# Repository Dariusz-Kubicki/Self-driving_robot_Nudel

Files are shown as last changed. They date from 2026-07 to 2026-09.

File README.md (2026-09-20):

# Self-driving_robot_Nudel

**Nudel** to mój pierwszy projekt robotyczny: czterokołowy robot mobilny budowany na bazie zestawu z AliExpress i rozwijany jako line follower. Jego pierwszym zadaniem jest samodzielne poruszanie się po czarnej linii przy użyciu czterech cyfrowych czujników podczerwieni.

Projekt nadal jest rozwijany. Robot poprawnie uruchamia napęd i reaguje na czujniki, ale algorytm oraz wartości PWM wymagają dalszego strojenia na większym torze z łagodniejszymi zakrętami.

## Aktualny stan projektu

- podwozie 4WD zostało złożone i okablowane;
- pierwotny sterownik L293D został zastąpiony modułem DRV8833;
- zamontowano wydrukowaną podstawkę Arduino i dystanse czujników IR;
- koszyk 4×AA został zastąpiony koszykiem 6×AA;
- Arduino otrzymało osobne zasilanie 9 V przez gniazdo DC;
- dodano kondensatory ograniczające zakłócenia zasilania;
- powstała plansza testowa z 12 połączonych kartek A4;
- działa podstawowy program reagujący na cztery czujniki IR;
- trwają testy prędkości i zachowania robota na zakrętach.

Najbliższy test zostanie wykonany na dużym, łagodnym okręgu. Obecny tor ma zbyt ciasne zakręty dla długiego podwozia 4WD, które podczas skręcania musi pokonać duże tarcie boczne czterech opon.

## Cel projektu

Celem projektu jest praktyczna nauka podstaw robotyki i zbudowanie pierwszego autonomicznego pojazdu. Podczas pracy uczę się:

- sterowania silnikami DC za pomocą mostka H;
- generowania sygnału PWM i doboru prędkości silników;
- konfiguracji oraz kalibracji cyfrowych czujników IR;
- projektowania algorytmu line followera;
- diagnozowania spadków napięcia, zakłóceń i resetów mikrokontrolera;
- lutowania, prowadzenia przewodów i prototypowania;
- projektowania prostych elementów mechanicznych do druku 3D;
- dokumentowania kolejnych wersji konstrukcji i kodu.

W przyszłości planuję rozbudować Nudla o czujnik odległości HC-SR04, serwomechanizm SG90, a w dalszej perspektywie również kamerę.

### Skąd nazwa „Nudel”?

Nazwa robota upamiętnia mojego pierwszego kota, który wabił się Nudel. Uznałem, że będzie to dobre imię dla mojego debiutanckiego projektu robotycznego.

## Elementy projektu

Podstawą konstrukcji jest [zestaw z AliExpress](https://pl.aliexpress.com/item/1005002223616703.html), który został przeze mnie zmodyfikowany.

### Elementy pochodzące z zestawu

- klon Arduino UNO R3;
- cztery czujniki IR;
- płytka z komparatorami i potencjometrami do regulacji czujników;
- cztery silniki DC z przekładniami TT;
- czujnik ultradźwiękowy HC-SR04;
- serwomechanizm SG90;
- nakładka Arduino UNO Sensor Shield V5.0;
- akrylowe podwozie, koła i elementy montażowe;
- pierwotny koszyk na cztery baterie AA.

### Elementy dodane lub zmienione

- dwukanałowy sterownik silników DRV8833;
- koszyk na sześć baterii AA;
- osobne źródło 9 V dla Arduino;
- kondensatory filtrujące zasilanie;
- wydrukowana podstawka pod Arduino;
- wydrukowane dystanse obniżające czujniki IR;
- nowe przewody i poprawione połączenia lutowane.

## Druk 3D

Drukarkę 3D kupiłem już w trakcie budowy robota. Wykorzystałem ją do wykonania elementów dopasowanych do tej konstrukcji:

- [podstawka pod Arduino](Ard.stl);
- [dystanse do czujników IR](dystanse_do_sensorow.stl).

Podstawka porządkuje montaż elektroniki, a dystanse umieszczają czujniki bliżej podłoża. Zbyt duża odległość od planszy powodowała niestabilne wykrywanie czarnej taśmy.

Elementy drukowane nie są niezbędne. Arduino można przykręcić bezpośrednio do podwozia lub zastosować gotowy uchwyt, a wysokość czujników ustawić za pomocą zwykłych dystansów montażowych.

## Zasilanie

Napęd i elektronika korzystają obecnie z oddzielnych źródeł zasilania:

```text
6×AA ───────────────> zasilanie silników przez DRV8833

9 V przez gniazdo DC ─> Arduino UNO i układ sterujący

GND Arduino ─────────> GND DRV8833
```

Wspólna masa jest potrzebna, aby sygnały sterujące z Arduino miały prawidłowy poziom odniesienia.

Rozdzielenie zasilania rozwiązało problem resetowania Arduino podczas jednoczesnego uruchamiania silników. Wcześniej impuls prądowy napędu powodował spadek napięcia całego układu. Zwiększenie samej liczby baterii nie wystarczyło, ponieważ problem dotyczył także wydajności prądowej i wspólnej linii zasilania.

## Połączenia z Arduino

Aktualny program korzysta z następujących pinów:

| Element | Pin Arduino |
|---|---:|
| Lewy czujnik IR | 8 |
| Środkowy lewy czujnik IR | 7 |
| Środkowy prawy czujnik IR | 4 |
| Prawy czujnik IR | 2 |
| DRV8833 — LIN1 | 5 |
| DRV8833 — LIN2 | 3 |
| DRV8833 — RIN1 | 9 |
| DRV8833 — RIN2 | 6 |

Wszystkie cztery wejścia sterownika silników podłączono do pinów obsługujących PWM w Arduino UNO. Dzięki temu program może regulować prędkość obu stron napędu oraz zmieniać ich kierunek.

## Oprogramowanie

Aktualny kod znajduje się w pliku [Robot_Nudel.ino](Robot_Nudel.ino).

Program:

1. odczytuje stany czterech czujników IR;
2. wybiera jazdę prosto, lekką korektę, mocny skręt albo zatrzymanie;
3. steruje lewą i prawą stroną napędu przez DRV8833;
4. podczas mocnego skrętu może napędzać obie strony w przeciwnych kierunkach, aby zmniejszyć promień obrotu.

Aktualne wartości PWM są eksperymentalne. Po ustabilizowaniu zasilania silniki zaczęły pracować znacznie pewniej, dlatego wcześniejsze ustawienia prędkości trzeba było dobrać ponownie.

### Ważna uwaga dotycząca czujników

Stan logiczny czujnika zależy od ustawienia komparatorów i zastosowanego modułu. Przed dalszym strojeniem programu trzeba jednoznacznie sprawdzić w monitorze portu szeregowego, jaki stan (`LOW` lub `HIGH`) odpowiada czarnej taśmie, a jaki białemu podłożu. Kod i opis tej logiki powinny być ze sobą zgodne.

## Proces budowy

### 1. Złożenie podwozia

Prace rozpocząłem od zamontowania przekładni TT, silników, kół i czujników IR.

Z podwoziem wiąże się zabawna historia. Dopiero po pełnym złożeniu konstrukcji zorientowałem się, że akryl jest przezroczysty. Wcześniej uznałem brązową folię ochronną za docelowy kolor materiału, dlatego musiałem rozmontować całość, aby ją usunąć.

Podczas pierwszego montażu pominąłem także gumowe elementy zabezpieczające silniki. Założyłem je później pęsetą na niemal ukończonym robocie. Konstrukcja i tak została następnie ponownie rozebrana podczas wymiany sterownika silników.

### 2. Montaż czujników

Czujniki zamontowane bezpośrednio przy podwoziu znajdowały się zbyt wysoko nad planszą. Zaprojektowałem więc dystanse, które obniżyły moduły i poprawiły powtarzalność odczytów.

Podczas wykonywania otworów dwukrotnie uszkodziłem akrylowe podwozie. Pęknięcia udało się skleić, ale ten etap pokazał, że akryl wymaga ostrożnej obróbki. Najbezpieczniej wiercić na małych obrotach, podeprzeć materiał, zacząć od niewielkiego otworu prowadzącego i stopniowo zwiększać średnicę. Silne podgrzewanie może odkształcić lub uszkodzić tworzywo.

### 3. Montaż elektroniki

Pierwsza wersja powstała bez wcześniejszego prototypu. Elementy były od razu lutowane i montowane na docelowym podwoziu. Utrudniło to znalezienie błędów oraz wymusiło kilkukrotne rozbieranie robota.

Po wymianie przewodów, sterownika silników i sposobu zasilania połączenia zaczęły działać stabilniej.

### 4. Budowa toru testowego

Do testów powstała duża plansza z 12 kartek A4 ułożonych w prostokąt i połączonych ze sobą. Trasę wykonano z czarnej taśmy izolacyjnej.

Pierwszy tor zawierał zakręty zbyt ciasne dla obecnej konstrukcji. Czterokołowe podwozie jest długie, a podczas skręcania wszystkie koła pozostają ustawione równolegle, przez co opony muszą częściowo ślizgać się po podłożu. Kolejna trasa będzie miała kształt dużego, łagodnego okręgu.

## Napotkane problemy

### 1. Brak odpowiedniego sterownika silników

W zestawie nie znalazł się sterownik napędu. Pierwsza wersja robota korzystała więc z układu L293D pochodzącego z zestawu kursu Arduino Forbota.

L293D powodował duży spadek napięcia na wyjściach i nie radził sobie dobrze z czterema silnikami TT połączonymi parami. Robot poruszał się bardzo wolno i nie miał wystarczającego momentu do skręcania. Przy lekkim napędzie 2WD układ mógłby działać, ale zależy to od poboru prądu konkretnych silników, szczególnie podczas rozruchu i zablokowania wału.

**Rozwiązanie:** L293D został zastąpiony modułem DRV8833, który ma mniejsze straty napięcia i lepiej nadaje się do sterowania tym napędem.

### 2. Słabe i zbyt krótkie przewody

Pierwsze przewody pochodziły z taniego zestawu. Źle znosiły lutowanie, a ich końce łatwo się uszkadzały. Część odcinków została także przycięta bez odpowiedniego zapasu, przez co po montażu były naprężone i odrywały się od połączeń.

**Rozwiązanie:** zastosowanie lepszych przewodów, pozostawienie zapasu długości oraz mechaniczne odciążenie połączeń.

### 3. Brak prototypowania

Układ został od razu zlutowany w docelowej formie. Każda większa zmiana wymagała więc rozlutowania przewodów i częściowego demontażu robota.

**Wniosek:** przed montażem docelowym warto sprawdzić osobno zasilanie, każdy kanał sterownika, kierunki wszystkich silników i odczyty czujników.

### 4. Resetowanie Arduino podczas rozruchu

Po zamontowaniu DRV8833 silniki zaczęły pobierać większy prąd przy ruszaniu. Przy wspólnym zasilaniu powodowało to spadki napięcia i wielokrotne restarty Arduino, widoczne w monitorze portu szeregowego jako powtarzający się komunikat `Start`.

Dodanie kondensatorów ograniczyło zakłócenia, ale nie usunęło głównej przyczyny.

**Rozwiązanie:** oddzielenie zasilania Arduino od obwodu silników. Arduino jest obecnie zasilane napięciem 9 V przez gniazdo DC, a napęd z koszyka 6×AA. Oba obwody mają wspólną masę.

### 5. Dobór prędkości i promienia zakrętów

Po ustabilizowaniu zasilania silniki zaczęły osiągać znacznie większą prędkość. Wartości PWM, które wcześniej ledwo poruszały robotem, przestały odpowiadać nowym warunkom testu.

Dodatkowo pierwszy tor miał zbyt mały promień zakrętów dla podwozia 4WD.

**Obecne rozwiązanie:** zmniejszenie PWM, użycie przeciwnego kierunku obrotu stron podczas mocnego skrętu oraz przygotowanie większego toru z łagodniejszymi łukami.

## Uruchomienie

1. Otwórz plik `Robot_Nudel.ino` w Arduino IDE.
2. Wybierz płytkę `Arduino Uno` i właściwy port szeregowy.
3. Wgraj program.
4. Sprawdź położenie robota oraz czujników przed włączeniem zasilania silników.
5. Umieść dwa środkowe czujniki nad linią, a skrajne nad jasnym tłem.
6. Włącz zasilanie napędu i obserwuj zachowanie na prostym odcinku przed testem pełnej trasy.

## Plan dalszych prac

- wykonać duży tor w kształcie łagodnego okręgu;
- potwierdzić poziomy logiczne czujników na czarnej i białej powierzchni;
- dostroić wartości PWM dla jazdy prosto oraz obu rodzajów skrętu;
- uzyskać kilka powtarzalnych pełnych okrążeń bez ręcznej pomocy;
- uporządkować i dodatkowo zabezpieczyć przewody;
- zastąpić testowe zasilanie Arduino rozwiązaniem docelowym;
- dodać HC-SR04 i SG90;
- rozważyć późniejszą rozbudowę o kamerę.

## Najważniejsze wnioski

- liczba baterii nie określa sama w sobie wydajności zasilania;
- prąd rozruchowy silników może resetować mikrokontroler;
- układ może działać bez obciążenia, a zawodzić po postawieniu robota na podłożu;
- kondensatory pomagają ograniczyć zakłócenia, ale nie zastępują poprawnego zasilania;
- elementy trzeba testować osobno przed zlutowaniem całego układu;
- w podwoziu 4WD geometria toru ma duży wpływ na możliwość skręcania;
- po każdej zmianie sprzętowej parametry programu mogą wymagać ponownego strojenia.

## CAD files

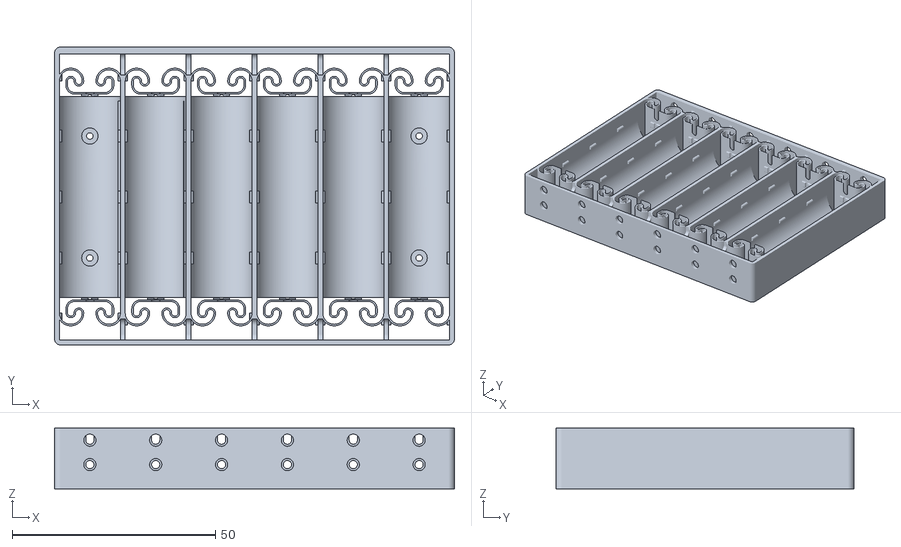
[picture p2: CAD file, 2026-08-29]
AAA_HolderX6.stl
98.4 x 73.3 x 15.0

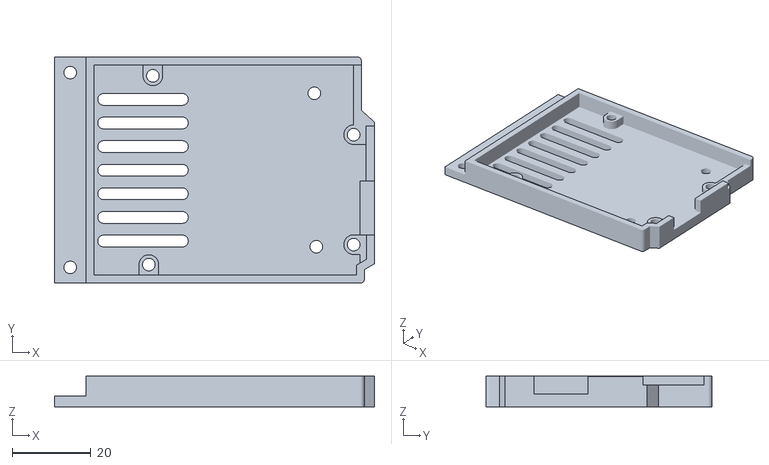
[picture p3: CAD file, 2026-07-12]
Ard.stl
81.3 x 57.5 x 7.80

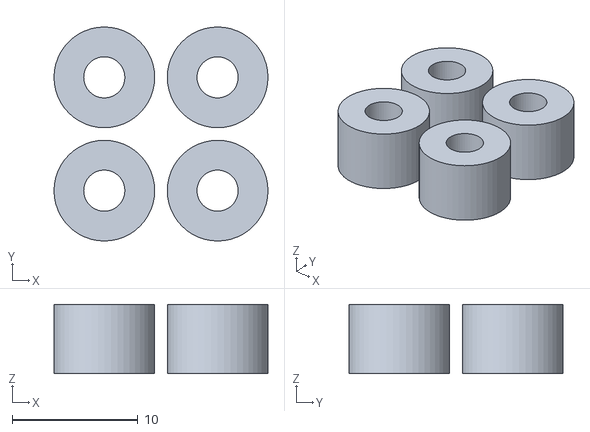
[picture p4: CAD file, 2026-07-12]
dystanse_do_sensorow.stl
17.0 x 17.0 x 5.50

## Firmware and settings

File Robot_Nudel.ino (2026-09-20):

// Piny czujników IR
#define IR_Lewy 8
#define IR_Srodek_Lewy 7
#define IR_Srodek_Prawy 4
#define IR_Prawy 2

// Piny silników
#define LIN1 5
#define LIN2 3
#define RIN1 9
#define RIN2 6

void setup() {
  pinMode(IR_Lewy, INPUT);
  pinMode(IR_Srodek_Lewy, INPUT);
  pinMode(IR_Srodek_Prawy, INPUT);
  pinMode(IR_Prawy, INPUT);

  pinMode(LIN1, OUTPUT);
  pinMode(LIN2, OUTPUT);
  pinMode(RIN1, OUTPUT);
  pinMode(RIN2, OUTPUT);

  digitalWrite(LIN1, LOW);
  digitalWrite(LIN2, LOW);
  digitalWrite(RIN1, LOW);
  digitalWrite(RIN2, LOW);

  Serial.begin(9600);
  Serial.println("Start");
}

void loop() {
  // Algorytm sterowania
  if (digitalRead(IR_Srodek_Prawy) == HIGH && digitalRead(IR_Srodek_Lewy) == HIGH && digitalRead(IR_Prawy) == HIGH && digitalRead(IR_Lewy) == HIGH) {
    stop();
  } else if (digitalRead(IR_Srodek_Prawy) == HIGH && digitalRead(IR_Srodek_Lewy) == HIGH) {
    doPrzodu();
  } else if (digitalRead(IR_Srodek_Prawy) == HIGH) {
    lekkoLewo();
  } else if (digitalRead(IR_Srodek_Lewy) == HIGH) {
    lekkoPrawo();
  } else if (digitalRead(IR_Prawy) == HIGH) {
    lewo();
  } else if (digitalRead(IR_Lewy) == HIGH) {
    prawo();
  } else {
    stop();
  }

}

// Sterowanie
void doPrzodu () {
  analogWrite(LIN1, 50);
  analogWrite(RIN1, 50);
  digitalWrite(LIN2, LOW);
  digitalWrite(RIN2, LOW);
  delay(0);
}

void lekkoPrawo() {
  analogWrite(LIN1, 80);
  analogWrite(RIN1, 0);
  digitalWrite(LIN2, LOW);
  digitalWrite(RIN2, LOW);
  delay(0);
}

void lekkoLewo() {
  analogWrite(LIN1, 0);
  analogWrite(RIN1, 80);
  digitalWrite(LIN2, LOW);
  digitalWrite(RIN2, LOW);
  delay(0);
}

void lewo(){
  analogWrite(LIN2, 100);
  analogWrite(RIN1, 110);
  digitalWrite(LIN1, LOW);
  digitalWrite(RIN2, LOW);
  delay(0);
}

void prawo(){
  analogWrite(LIN1, 110);
  analogWrite(RIN2, 100);
  digitalWrite(LIN2, LOW);
  digitalWrite(RIN1, LOW);
  delay(0);
}

void stop() {
  digitalWrite(LIN1, LOW);
  digitalWrite(LIN2, LOW);
  digitalWrite(RIN1, LOW);
  digitalWrite(RIN2, LOW);

}

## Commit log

2026-07-12 Enhance README with project details and challenges
    Updated project documentation with additional details about components, 3D printing usage, and encountered issues during assembly.
2026-07-14 Document issues faced in robot assembly
    Added encountered problems and solutions during robot construction.
